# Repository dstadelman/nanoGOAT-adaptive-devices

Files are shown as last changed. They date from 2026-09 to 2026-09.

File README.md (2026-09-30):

# nanoGOAT Adaptive Devices

Open hardware that connects the [nanoGOAT AAC](https://nanogoat.com) app to the
physical world. Everything here is low-voltage, battery-powered, and built from
off-the-shelf parts so it can be reproduced at a kitchen table.

> **New here? Start with the [Adaptive Controller guide](adaptive-controller/README.md).**
> It takes you from nothing installed to a XIAO ESP32C6 board you can control
> over Bluetooth, and says which steps have not been tried yet.

Devices fall into two directions:

| Direction | Device | What it does | Status |
|---|---|---|---|
| **Output** (app → world) | [`adaptive-controller/`](adaptive-controller/) | A Bluetooth box with a 3.5mm jack. The app tells it to close a relay, which runs any switch-adapted toy (first up: a bubble machine). | Firmware works on a bare board; box build in progress |
| **Input** (world → app) | [`switch-interface/`](switch-interface/) | Lets a standard accessibility switch (e.g. a Big Red button) drive the tablet for switch scanning. | Idea |

## Vocabulary

- **Accessibility switch** (or *adaptive switch*): the big, easy-to-press button
  a person uses, e.g. AbleNet Big Red or Jelly Bean. It is just a momentary
  contact on a 3.5mm mono plug.
- **Switch-adapted toy**: a battery toy with a 3.5mm mono jack wired across its
  on/off switch. Shorting tip to sleeve runs the toy.
- **Switch interface**: a box that turns switch presses into input a tablet
  understands.

## Safety

Low voltage and battery toys only. Nothing mains-powered, ever.

## License

MIT, see [LICENSE](LICENSE).

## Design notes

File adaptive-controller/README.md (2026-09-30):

# Adaptive Controller

A small battery-powered Bluetooth box that lets the
[nanoGOAT AAC](https://nanogoat.com) app run a switch-adapted toy. A child taps
"more bubbles" on their communication board, the box closes a switch for a few
seconds, and the bubble machine runs.

The box plugs into a toy through a standard 3.5mm headphone-size jack. This is
the same plug that accessibility switches such as the AbleNet Big Red use.

## Where this project is

The firmware runs on a bare XIAO ESP32C6 board, and a computer can control it
over Bluetooth. The box itself (relay, battery, jack, enclosure) is designed
but not yet built.

This guide lists only steps that were done and checked, on **Windows 11**.
[What has not been tried yet](#what-has-not-been-tried-yet) lists the rest.

## 1. What you need

| Item | Notes |
|---|---|
| **Seeed Studio XIAO ESP32C6** | Make sure it says **ESP32C6**. Other XIAO boards need different settings. |
| **USB-C cable** | It must carry data, not only charge. |
| **A Windows computer** | About **8 GB** of free disk space for the tools, and Bluetooth for step 5. |

No soldering is needed for this guide. The board's small **orange LED** stands
in for the toy.

## 2. Install Arduino IDE

Arduino IDE turns the firmware source code into a program the board can run,
and copies it onto the board.

1. Download **Arduino IDE 2** from <https://www.arduino.cc/en/software> and
   install it. (Used here: version 2.3.10.)
2. Open it once, then close it.

Arduino IDE includes a command-line program, `arduino-cli`, which this guide
uses. On Windows it is at:

```
%LOCALAPPDATA%\Programs\Arduino IDE\resources\app\lib\backend\resources\arduino-cli.exe
```

The commands below write `arduino-cli`. Type the full path above in its place,
in quotes, or add that folder to your PATH.

## 3. Add support for the ESP32-C6 chip

Arduino IDE only knows Arduino's own boards. The XIAO ESP32C6 uses an
**Espressif ESP32-C6** chip, so you install Espressif's **esp32** package. It
contains the **RISC-V compiler** that builds programs for the ESP32-C6's
processor, Espressif's chip libraries (including Bluetooth), and the tool that
copies programs onto the board.

In a terminal, run:

```sh
arduino-cli core install esp32:esp32 --additional-urls https://espressif.github.io/arduino-esp32/package_esp32_index.json
```

What to expect:

- The download is about **2 GB**. The installed package takes about **6.5 GB**.
  It includes compilers for other ESP32 chips that this project does not use.
- The largest file is the RISC-V compiler, about 670 MB. Here, the download
  failed partway once (`Download failed ... connection was aborted`). Running
  the same command again finished the install.

**It worked when** `arduino-cli core list` shows `esp32:esp32` (used here:
version 3.3.12).

## 4. Put the firmware on the board

"Firmware" is the program that runs on the board. It is in
[`firmware/adaptive_controller/`](firmware/adaptive_controller/).

1. Download this repository: on GitHub, click **Code → Download ZIP** and
   unzip it. Open a terminal in the `adaptive-controller` folder.
2. Plug the XIAO into the computer.
3. Find its port:

   ```sh
   arduino-cli board list
   ```

   The board appears as a `Serial Port (USB)`, for example `COM3`.
4. Build and upload, using your port in place of `COM3`:

   ```sh
   arduino-cli compile -b esp32:esp32:XIAO_ESP32C6:CDCOnBoot=cdc -u -p COM3 firmware/adaptive_controller
   ```

   `CDCOnBoot=cdc` lets the board print messages to the computer over USB.
   The first build takes a few minutes.

**It worked when** the output ends with `Hash of data verified.` and
`Hard resetting via RTS pin...`. No buttons on the board need to be pressed.

## 5. Check that it works

Install Python 3 from <https://www.python.org/downloads/>, then install the two
libraries the test scripts use:

```sh
pip install pyserial bleak
```

### 5a. Ask the board how it is

```sh
python tools/status.py COM3
```

**It worked when** you see a line like:

```
[  35686] STATUS fw=0.1.0 ble=advertising relay=off mode=idle last_off=boot battery_mv=0
```

`ble=advertising` means the board is waiting for a Bluetooth connection as
**nanoGOAT Controller**. `relay=off` means the toy output is off.

### 5b. Run the full Bluetooth test

[`tools/ble_smoke_test.py`](tools/ble_smoke_test.py) connects to the board over
the computer's Bluetooth, sends every command, and checks every safety rule it
can see from outside: a timed run ends on its own, the 60-second limit holds,
and the output turns off when the connection drops.

```sh
python tools/ble_smoke_test.py --serial COM3
```

Add `--long` to also wait out the 60-second maximum run.

**It worked when** the last line says `ALL CHECKS PASSED`. While it runs, the
orange LED turns on and off.

### 5c. Measure how fast it answers

A child's tap has to start the toy in under 500 ms
([`_specs/PRODUCT.md`](_specs/PRODUCT.md) §4a).
[`tools/latency.py`](tools/latency.py) sends 20 short runs and times each one,
from sending the command until the box reports the relay is on.

```sh
python tools/latency.py
```

Measured here, over 100 runs from a Windows 11 PC: median **57 ms**, slowest
**139 ms**. The box's own log shows each relay closing in the same millisecond
its command arrives; the rest is Bluetooth.

The box accepts **one connection at a time**. If a tool says no Adaptive
Controller was found, a phone or another program is probably connected to it.
`python tools/status.py COM3` shows `ble=connected` in that case.

## What the lights mean

| Light | Meaning |
|---|---|
| **Orange** on | The toy output is on. With a toy plugged in, the toy runs. |
| **Orange** off | The toy output is off. |
| **Red** | Not yet identified. |

## Problems seen so far

| Problem | What fixed it |
|---|---|
| The esp32 install stopped with `Download failed` | Running the same install command again. |
| The board restarted every time a script closed its USB connection | On this chip, two USB control lines double as the reset line. The scripts in `tools/` now release them in an order that does not restart the board. A program that closes the port without doing this restarts the board; that is harmless. |

## What has not been tried yet

- Installing the board support and uploading through the Arduino IDE's
  windows and menus (this guide used the IDE's `arduino-cli`)
- The Arduino IDE Serial Monitor
- Controlling the board from a phone (for example with nRF Connect)
- Controlling the board from the nanoGOAT AAC app on a real phone or tablet
- macOS and Linux
- Wiring the relay, battery, jack, and status LED, and running a real toy
- Battery voltage measurement (the firmware reports `battery_mv=0` until the
  divider is built)

## Reference

| Path | Contents |
|---|---|
| [`_specs/`](_specs/README.md) | What the box does and must never do. The specs are normative: if anything else disagrees with them, the spec wins. |
| [`_specs/SAFETY.md`](_specs/SAFETY.md) | Read before connecting a battery or a toy |
| [`_specs/HARDWARE.md`](_specs/HARDWARE.md) | Pins, power, jack wiring, netlist |
| [`_specs/BOM.md`](_specs/BOM.md) | Parts list |
| [`_specs/BLE_PROTOCOL.md`](_specs/BLE_PROTOCOL.md) | Bluetooth commands and status format |
| [`kicad/`](kicad/) | KiCad 10 schematic ([PDF](kicad/adaptive-controller.pdf)) |
| [`firmware/`](firmware/) | Arduino firmware |
| [`tools/`](tools/) | `status.py`, `ble_smoke_test.py`, `latency.py` |

### Edit the schematic

Install [KiCad 10](https://www.kicad.org/download/) and open
`kicad/adaptive-controller.kicad_pro`. After editing, check it and re-export.
Run these in `kicad/`. On Windows, `kicad-cli` is in
`%LOCALAPPDATA%\Programs\KiCad\10.0\bin`.

```sh
kicad-cli sch erc adaptive-controller.kicad_sch
kicad-cli sch export svg -o . adaptive-controller.kicad_sch
kicad-cli sch export pdf -o adaptive-controller.pdf adaptive-controller.kicad_sch
kicad-cli sch export netlist -o adaptive-controller.net adaptive-controller.kicad_sch
python check_netlist.py adaptive-controller.net
```

### Build phases

Each phase adds its spec to `_specs/` and stops for review.

1. Hardware design and schematic ← *in review*
2. Toy adaptation: add a 3.5mm jack to the bubble machine
3. Firmware and BLE protocol ← *runs on a bare board; Bluetooth test passes*
4. Bench test
5. Enclosure layout

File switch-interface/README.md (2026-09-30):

# Switch Interface (idea, not started)

The input direction: a person presses an accessibility switch, and the tablet
treats it as a scanning input.

## Notes to resolve before designing

- **Where scanning lives.** Android (Switch Access) and iOS/iPadOS (Switch
  Control) both do switch scanning at the OS level. They accept a Bluetooth
  keyboard as the switch source. A box that shows up as a BLE HID keyboard and
  sends one key per switch press would then work with any app, with no app
  changes. The catch is that OS scanning only reaches controls the app exposes
  to the accessibility tree.
- **In-app scanning.** No switch-scanning code was found in `nanoGOAT-aac-app`
  as of 2026-09-30. If in-app scanning is wanted (it can be tuned for AAC grids),
  it's an app feature, and this box would still just be a keyboard.
- **Hardware overlap.** The same XIAO ESP32C6 plus a 3.5mm jack *input* (no
  relay) likely covers it. Two jacks give two-switch scanning (move + select).

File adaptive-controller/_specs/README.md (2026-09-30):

# `_specs` — Adaptive Controller specifications

**This folder is normative.** If firmware, wiring, issues, or videos disagree
with a spec, the spec wins. Fix the build or change the spec first.

## Folder laws

1. **Spec before build.** A behavior or wiring change starts as a spec edit,
   then an issue, then the build.
2. **Present tense only.** Specs describe what is true. No changelogs,
   strike-throughs, or "used to be." History lives in git and issues.
3. **One owner per fact.** Each fact has one spec. Other specs link to it
   instead of restating it.
4. **Issues name gaps.** Specs state the desired law. Issues state where the
   physical build or firmware diverges.

## Specs in this folder

| Spec | Owns |
|---|---|
| [PRODUCT](PRODUCT.md) | Goal, users, operating modes, status LED meanings, how the box is used day to day |
| [SAFETY](SAFETY.md) | Safety invariants that every other spec, the firmware and the wiring obey |
| [HARDWARE](HARDWARE.md) | Pin assignments, power path, current budget, output jack, netlist |
| [BOM](BOM.md) | Parts list and procurement status |
| [BLE_PROTOCOL](BLE_PROTOCOL.md) | GATT service, commands, and status format: the app ↔ box contract |
| [FIRMWARE](FIRMWARE.md) | Platform, timing values, state machine, indicators, serial log |

Specs still to come, one per build phase: toy adaptation (bubble machine),
bench test, enclosure.

## Precedence

| Domain | Winner |
|---|---|
| Anything that can leave a toy running or hurt someone | SAFETY |
| What the user sees and does | PRODUCT |
| What is wired to what | HARDWARE |
| Bytes between app and box | BLE_PROTOCOL |
| Timing values and firmware behavior | FIRMWARE |
| What to buy | BOM |

The KiCad schematic in [`../kicad/`](../kicad/) follows HARDWARE. If the two
disagree, HARDWARE wins.

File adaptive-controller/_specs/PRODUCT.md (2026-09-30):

# PRODUCT — Adaptive Controller

## 1. Goal

The Adaptive Controller lets the nanoGOAT AAC app run a switch-adapted toy.
A child taps a word such as "more bubbles" on their AAC board, and the toy runs.
The request is communicated with language, and the world responds.

## 2. What it is

A small battery-powered Bluetooth Low Energy (BLE) box with one 3.5mm mono
output jack. When the app commands it, the box closes a relay across the jack's
tip and sleeve for a bounded time.

This is the same electrical interface every commercial accessibility switch
uses (e.g. AbleNet Big Red). To a toy, the box is indistinguishable from a
person pressing a switch. Therefore:

- Any toy adapted for the box also works with an ordinary accessibility switch.
- Any commercially switch-adapted toy works with the box.

## 3. Users

| User | Needs |
|---|---|
| AAC user (child) | Taps a word; the toy responds quickly and reliably. |
| Caregiver / therapist | Charges the box, plugs in a toy, pairs it in the app, and trusts it will not leave a toy running. |
| Maker | Builds the box from the specs in this folder with hand tools and a soldering iron. |

## 4. Operating modes

The app selects the mode per command. [SAFETY](SAFETY.md) bounds every mode.

| Mode | Pairs with | Behavior |
|---|---|---|
| **Timed** (default) | A single word ("more bubbles") | The toy runs for a set duration, then stops. The box owns the timer; the app sends one command. |
| **Latched** | A word pair ("go" / "stop") | The toy runs until a stop command, disconnect, or the maximum on-time, whichever comes first. |
| **Direct** | Press-and-hold in the app | The toy runs only while the app keeps sending heartbeats. It stops as soon as heartbeats stop. |

The timed duration is a setting stored on the box. It is never longer than the
maximum on-time in [SAFETY](SAFETY.md).

## 4a. Response time

A child taps a word and expects the toy to answer at once. A delay the child
can notice breaks the link between the word and the result.

| Span | Limit |
|---|---|
| Tap on the AAC board → toy starts | under **500 ms** |
| Command arrives at the box → relay closed | under **50 ms** |

The app holds the connection open before the child taps. Connecting takes
seconds, so a tap never waits for a connection. Every command is sent the
moment it is tapped, never behind an earlier command that has not completed.

## 5. Status LED

One LED on the outside of the box shows the state.

| Pattern | Meaning |
|---|---|
| Slow blink | On, advertising, waiting for the app |
| Solid | Connected to the app |
| Quick flash | Relay on (toy running) |
| Rapid blink | Battery low; charge soon |
| Off | Power switch off, or battery empty |

## 6. Everyday use

- **Power:** a slide switch on the box turns it on and off. Off fully
  disconnects the battery.
- **Charging:** USB-C. The power switch must be **on** to charge, because the
  charger is on the controller board, downstream of the switch. The box works
  normally while charging.
- **Connecting a toy:** a 3.5mm mono cable runs from the box's jack to the toy's
  jack.
- **Connecting the app:** the app scans for the box and connects directly. The
  box needs no pairing in the phone's Bluetooth settings.

## 7. Scope

In scope: one output, battery toys, control from the nanoGOAT AAC app.

Out of scope: nanoGOAT app changes (the BLE protocol spec defines the contract
the app implements), multiple outputs, a physical switch input on the box,
custom PCB, and 3D-printed enclosure.

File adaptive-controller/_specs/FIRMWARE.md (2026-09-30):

# FIRMWARE — Adaptive Controller

Firmware behavior, timing values, and build. The wire format is owned by
[BLE_PROTOCOL](BLE_PROTOCOL.md); pins by [HARDWARE](HARDWARE.md); the
invariants it enforces by [SAFETY](SAFETY.md).

## 1. Platform

- **Arduino framework** on the Espressif `esp32` core, board **XIAO_ESP32C6**,
  built with `arduino-cli`. Seeed documents the XIAO ESP32C6 Arduino-first, the
  core includes BLE, and viewers can build it from the Arduino IDE.
- Source: [`../firmware/adaptive_controller/`](../firmware/adaptive_controller/).
- USB CDC on boot is enabled, so serial logs appear on the USB-C port.

## 2. Values

| Value | Setting |
|---|---|
| Hard maximum on-time | **60 s**, compiled in |
| Default timed duration | **5 s**, changeable with SET_DEFAULT_DURATION |
| Heartbeat timeout (direct mode) | **1500 ms** |
| Low-battery warning | below **3.60 V** |
| Low-battery cutoff (relay refuses to turn on) | below **3.40 V** |
| STATE notify while on | every **1 s** |

## 3. State machine

One loop owns the relay pin. Every path that turns the relay on goes through a
single function that checks the battery cutoff and sets a deadline no later
than *now + hard maximum*. The loop turns the relay off when any deadline passes
(timer, maximum on-time, heartbeat) and records the reason.

| From | Event | To |
|---|---|----|
| any | boot | idle (relay off, reason `boot`) |
| idle | RUN_TIMED / RUN_LATCHED / TOGGLE / HOLD | timed / latched / latched / direct |
| on (any mode) | another run command | the new mode; deadlines recomputed; maximum on-time counts from this command |
| on (any mode) | OFF, TOGGLE, deadline passed, disconnect, battery below cutoff, error | idle |

The first statement in `setup()` drives the relay pin low. The hardware
pull-down ([HARDWARE](HARDWARE.md) §3) covers the time before that.

## 4. Indicators

- **Status LED (D9):** the patterns in [PRODUCT](PRODUCT.md) §5.
- **Onboard user LED (GPIO15):** mirrors the relay. It is lit while the relay
  is on. This lets the firmware and app be tested on a bare XIAO with nothing
  wired to it.

## 5. Battery sensing

Battery sensing is a build option, `BATTERY_SENSE`. With it off (bare-board
builds without the divider), `battery_mv` reports `0` and the low-battery rules
are skipped. With it on, the firmware averages 16 ADC samples of VSENSE and
doubles them (1:2 divider).

## 6. Serial log

115200 baud over USB. One line per event, prefixed with milliseconds since
boot, so a test harness can parse it:

```
[   1234] BOOT fw=0.1.0 proto=1
[   1240] ADV start
[   5012] CONNECT
[   6100] CMD RUN_TIMED 5000
[   6100] RELAY ON mode=timed remaining=5000
[  11100] RELAY OFF reason=timer
[  15000] DISCONNECT
```

Every relay transition, command, connection change, and rejected command is
logged.

Any input received over serial prints one `STATUS` line with the firmware
version, connection state, relay state, and battery reading. A person with a
Serial Monitor open can confirm the board is alive without pressing a button:

```
[  81234] STATUS fw=0.1.0 ble=advertising relay=off mode=idle last_off=boot battery_mv=0
```

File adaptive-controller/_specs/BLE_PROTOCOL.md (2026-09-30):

# BLE_PROTOCOL — Adaptive Controller

The wire contract between the box and any app. The nanoGOAT AAC app, nRF
Connect, and test scripts all speak exactly this. Timing values and the state
machine behind it are owned by [FIRMWARE](FIRMWARE.md).

## 1. Discovery and connection

- The box is a BLE peripheral. It accepts **one connection at a time** and
  resumes advertising when that connection ends.
- The advertising packet carries the **service UUID**. The scan response carries
  the device name **`nanoGOAT Controller`**. Apps discover the box by filtering
  on the service UUID, not on the name.
- No bonding or OS pairing. An app scans, connects, and uses the service
  directly.

## 2. GATT

Every UUID shares the base `54ce0000-eae9-4eb4-8f51-34fbe6573f4c`. Only the
first 16 bits differ.

| Item | UUID | Properties |
|---|---|---|
| Service | `54ce0001-eae9-4eb4-8f51-34fbe6573f4c` | |
| CONTROL | `54ce0002-eae9-4eb4-8f51-34fbe6573f4c` | Write, Write Without Response |
| STATE | `54ce0003-eae9-4eb4-8f51-34fbe6573f4c` | Read, Notify |

All multi-byte integers are **little-endian**.

## 3. CONTROL: commands

Byte 0 is the opcode. The box ignores and logs malformed commands; the relay
state does not change.

| Opcode | Name | Payload | Effect |
|---|---|---|---|
| `0x01` | RUN_TIMED | `u32 duration_ms` | Relay on for `duration_ms`, clamped to the maximum on-time. `0` means the stored default duration. Restarts the timer if already on. |
| `0x02` | RUN_LATCHED | — | Relay on until OFF, disconnect, or the maximum on-time. |
| `0x03` | OFF | — | Relay off immediately. |
| `0x04` | TOGGLE | — | Relay off if on; otherwise RUN_LATCHED. |
| `0x05` | HOLD | — | Direct mode. Relay on, and stays on only while HOLD arrives at least once per heartbeat timeout. Each HOLD resets the heartbeat timer, not the maximum on-time. |
| `0x10` | SET_DEFAULT_DURATION | `u32 duration_ms` | Stores the default timed duration (persists across power cycles), clamped to the maximum on-time. |

Example: run for 5 seconds = `01 88 13 00 00`.

## 4. STATE: status

17 bytes. Readable at any time. Notified on every change, and once per second
while the relay is on.

| Offset | Type | Field | Values |
|---|---|---|---|
| 0 | u8 | protocol_version | `1` |
| 1 | u8 | relay | `0` off · `1` on |
| 2 | u8 | mode | `0` idle · `1` timed · `2` latched · `3` direct |
| 3 | u8 | last_off_reason | `0` boot · `1` OFF command · `2` timer done · `3` max on-time · `4` heartbeat lost · `5` disconnect · `6` low battery · `7` error |
| 4 | u32 | remaining_ms | Time until the relay turns off on its own; `0` when off |
| 8 | u16 | battery_mv | Battery voltage in mV; `0` when not measured |
| 10 | u32 | default_duration_ms | Stored default for RUN_TIMED |
| 14 | u16 | heartbeat_timeout_ms | HOLD must arrive within this interval |
| 16 | u8 | max_on_s | Hard maximum on-time, in seconds |

## 5. App obligations

- Treat STATE as the only truth about the relay. Never assume a command took
  effect until STATE says so.
- In direct mode, send HOLD at **no more than half** the heartbeat timeout.
- The app is never needed to turn the relay off. The box turns it off on its
  own ([SAFETY](SAFETY.md) §2).

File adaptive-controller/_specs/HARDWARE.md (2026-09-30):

# HARDWARE — Adaptive Controller

Electrical design of the box. Parts and their status live in [BOM](BOM.md);
the invariants this design serves live in [SAFETY](SAFETY.md).

Schematic

## 1. Blocks

| Ref | Block | Role |
|-----|---|---|
| U1 | Seeed XIAO ESP32C6 | BLE, timing, battery charging (USB-C) |
| K1 | 3V relay module, optocoupler input, high-level trigger | Closes the output contacts |
| J1 | 3.5mm mono panel jack with tip switch | Output to the toy |
| BT1 | 3.7V 1000mAh LiPo, protected | Power |
| SW1 | SPDT slide switch, used as SPST | Power on/off |
| LED1 | 5mm LED, red, green or yellow | Status ([PRODUCT](PRODUCT.md) §5) |

The relay contacts provide the isolation between the box and the toy. On this
style of 3V module, the optocoupler and the coil share the controller's ground,
so the optocoupler does not add galvanic isolation. It limits the GPIO load to
the optocoupler's LED current.

## 2. Pin assignments

| XIAO pin | GPIO | Net | Function |
|---|---|-----|---|
| D10 | GPIO18 | RELAY_IN | Relay module IN. High = relay on. |
| D9 | GPIO20 | LED_DRV | Status LED through 220Ω |
| D0 / A0 | GPIO0 | VSENSE | Battery voltage, ADC1_CH0 |
| D1 | GPIO1 | — | Reserved for a future switch input (LP GPIO, can wake from deep sleep) |
| D2–D8 | | — | Unused |

Excluded pins and the reason for each:

| Pins | Reason |
|---|---|
| GPIO4, 5, 8, 9, 15 | ESP32-C6 strapping pins. GPIO9 is the BOOT button; GPIO15 is the onboard user LED. |
| D6 / D7 (GPIO16/17) | UART0 TX/RX. The ROM bootloader transmits on TX at every reset. |
| GPIO3, GPIO14 | Onboard RF switch. GPIO3 low enables it; GPIO14 selects the antenna (low = onboard ceramic). Firmware leaves them at their defaults. |
| GPIO12, 13 | USB-Serial-JTAG: flashing and serial logs |

D9 and D10 sit on the same header edge as 3V3 and GND, so the relay's three
wires run in parallel.

Sources: [Seeed XIAO ESP32C6 wiki][seeed] (pin map, RF switch, battery
sensing); [ESP-IDF GPIO reference, ESP32-C6][idf-gpio] (strapping pins,
USB-JTAG pins, ADC1 channels).

## 3. Relay drive

- RELAY_IN has a **10kΩ pull-down (R3)** to GND. During reset, the GPIO is not
  yet driven, and the pull-down holds the relay off. With a weak internal
  pull-up active, the pull-down keeps the input well below the optocoupler's
  turn-on voltage.
- The relay module is powered from the XIAO **3V3** pin. The 5V pin exists only
  on USB power and would overdrive a 3V coil.
- **C2, 100µF** across the module's VCC/GND supplies the coil inrush locally.
  This prevents a brownout when the coil energizes during a BLE transmit burst
  on a partly discharged battery.

## 4. Current budget

| Load | Current | Basis |
|---|---|---|
| Relay coil (Songle SRD-03VDC-SL-C class) | ~120mA while on | [Datasheet via LCSC][relay] |
| Relay module IN (optocoupler LED) | A few mA from the GPIO | Module-dependent |
| Status LED | ~6mA | (3.3V − ~2.0V) / 220Ω. Blue and white LEDs (Vf ≈ 3V) are too dim at 220Ω and are not used. |
| R3 while relay on | 0.33mA | 3.3V / 10kΩ |
| Battery divider | ~20µA | 4.2V / 200kΩ |
| ESP32-C6 with BLE | Tens of mA | Measured in the bench test |

The relay's must-operate voltage is 75% of nominal (≈2.25V), so the relay keeps
working as the 3V3 rail follows a discharging battery below 3.3V.

## 5. Power path

```
BT1 + ──JST──► SW1 ──► VBAT ──► XIAO BAT+ pad
                         └────► R1 100k ─┬─ R2 100k ──► GND
                                         ├─ C1 100nF ─► GND
                                         └──────────► D0/A0 (VSENSE)
BT1 − ──JST────────────────────► XIAO BAT− pad = GND
USB-C ─► XIAO: powers the board and charges BT1 through the BAT pads
```

- SW1 disconnects the battery from everything, including the divider. Off
  draws zero current.
- Charging requires SW1 on ([PRODUCT](PRODUCT.md) §6).
- The XIAO ESP32C6 charges at about 100mA ([cnx-software][cnx]). A flat 1000mAh
  cell takes about 10 hours.
- R1/R2 form the 1:2 divider Seeed specifies for battery sensing on A0: 4.2V
  full charge reads as 2.1V. C1 gives the ADC a low-impedance source.

## 6. Output jack

J1 has three lugs: **sleeve**, **tip**, and **tip switch**. The tip switch rests
against the tip spring with no plug inserted, and opens when a plug is inserted.
Lug positions differ between vendors. The builder identifies them with a
multimeter:

1. Sleeve: continuity to the threaded bushing.
2. Tip and tip switch: continuity to each other with no plug inserted.
3. Tip: continuity to the plug tip with a plug inserted. The tip switch goes open.

Relay **COM → tip**, relay **NO → sleeve**. Relay NC and the tip-switch lug are
not connected. Relay contacts have no polarity, so the orientation does not
affect the toy.

The box has a female jack. A 3.5mm mono male-to-male cable connects it to the
toy's female jack. This is the same arrangement commercial switch extension
cables use.

## 7. Netlist

| Net | Connections |
|-----|---|
| VBAT_RAW | BT1 + · SW1 common |
| VBAT | SW1 outer pin A · U1 BAT+ · R1.1 |
| GND | BT1 − · U1 BAT− · U1 GND · K1 GND · R2.2 · C1.2 · R3.2 · LED1 cathode · C2 − |
| 3V3 | U1 3V3 · K1 VCC · C2 + |
| VSENSE | R1.2 · R2.1 · C1.1 · U1 D0 |
| RELAY_IN | U1 D10 · K1 IN · R3.1 |
| LED_DRV | U1 D9 · R4.1 |
| LED_A | R4.2 · LED1 anode |
| OUT_TIP | K1 COM · J1 tip |
| OUT_SLEEVE | K1 NO · J1 sleeve |
| No connect | K1 NC · J1 tip switch · SW1 outer pin B |

## 8. Facts pending measurement on the physical parts

| Fact | Checked in |
|---|---|
| Relay part number (coil current) | Bench test |
| Relay module IN current | Bench test |
| J1 lug identities | Build procedure |
| Battery connector type (JST-PH 2.0) and polarity | Build procedure |
| XIAO ESP32C6 charge current | Bench test |

[seeed]: https://wiki.seeedstudio.com/xiao_esp32c6_getting_started/
[idf-gpio]: https://docs.espressif.com/projects/esp-idf/en/stable/esp32c6/api-reference/peripherals/gpio.html
[relay]: https://www.lcsc.com/product-detail/C24585.html
[cnx]: https://www.cnx-software.com/2024/05/22/tiny-xiao-esp32c6-wifi-ble-and-802-15-4-iot-board-offers-up-to-16-gpio-pins/

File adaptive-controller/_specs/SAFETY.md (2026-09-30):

# SAFETY — Adaptive Controller

These invariants override every other spec. A design that satisfies a feature
but breaks an invariant is wrong.

## 1. Electrical scope

- The box switches **low-voltage, battery-powered toys only.** It is never
  connected to anything mains-powered, directly or through an adapter.
- The toy's circuit touches only the relay contacts. The toy's battery and the
  box's electronics share no conductor.

## 2. The relay is off unless something keeps it on

The box never depends on an "off" message arriving. The relay is **off** in
each of these conditions:

| Condition | Mechanism |
|---|---|
| Power-up, reset, or brownout | Hardware: 10kΩ pull-down on the relay input ([HARDWARE](HARDWARE.md) §3). Firmware drives the pin low before it does anything else. |
| Maximum on-time reached, in any mode | Firmware timer, independent of the app |
| BLE disconnect | Firmware |
| Direct mode heartbeat missed | Firmware |
| Any firmware error or unexpected state | Firmware fails to off |
| Battery below the cutoff voltage | Firmware refuses to turn the relay on |

## 3. Maximum on-time

- A single, compiled-in **hard maximum on-time** caps every activation in every
  mode. No command or stored setting can exceed it.
- The user-adjustable timed duration and any latched run are clamped to it.
- After the relay turns off at the hard maximum, it stays off until a new,
  separate command arrives. Nothing re-triggers it automatically.

The specific values (hard maximum, default timed duration, heartbeat interval,
battery cutoff) are owned by the firmware spec.

## 4. Battery

- The LiPo has its own protection circuit.
- JST battery connectors have no standard polarity. The battery connector's
  polarity is checked with a multimeter before the battery is ever connected
  to the controller board.
- The battery is never charged unattended while damaged, swollen, or hot.

## 5. Toy side

- Solder joints and the added jack inside a toy are sealed so bubble solution
  or other liquid cannot reach them.
- Adding the jack leaves the toy's own switch working.

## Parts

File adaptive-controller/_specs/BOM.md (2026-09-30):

# BOM — Adaptive Controller

Reference designators match [HARDWARE](HARDWARE.md).

**Status:** **Have** = in hand or ordered · **Planned** = chosen, not ordered ·
**Needed** = required by the design, not yet chosen or ordered.

## Box

| Ref | Part | Qty | Status |
|-----|---|-----|---|
| U1 | Seeed XIAO ESP32C6 | 1 | Have (3-pack) |
| K1 | AITRIP 3V 1-channel relay module, optocoupler, high-level trigger | 1 | Have (8-pack) |
| BT1 | 3.7V 1000mAh LiPo, 802540, protected, JST | 1 | Have |
| J1 | CESS 3.5mm mono panel jack with switch | 1 | Have (10-pack) |
| SW1 | SS12F15 SPDT mini slide switch | 1 | Have |
| | Female pin headers, to socket U1 | 2 × 7-pin | Have |
| | 22 AWG silicone stranded wire | | Have (6 colors) |
| LED1 | 5mm diffused LED, red, green or yellow | 1 | Planned |
| R4 | 220Ω resistor | 1 | Planned |
| | 5mm chrome LED bezel, 8mm hole | 1 | Planned |
| | uxcell 100×68×50mm clear ABS enclosure | 1 | Planned |
| | 5×7cm double-sided perfboard | 1 | Planned |
| | JST-PH 2.0 mating pigtail for BT1 | 1 | Planned (confirm the battery's connector is PH 2.0 first) |
| R3 | 10kΩ resistor | 1 | **Needed** |
| R1, R2 | 100kΩ resistor | 2 | **Needed** |
| C1 | 100nF ceramic capacitor | 1 | **Needed** |
| C2 | 100µF electrolytic capacitor, ≥10V | 1 | **Needed** |

A basic resistor and capacitor assortment kit covers every **Needed** item.

## Cables, toy and test equipment

| Part | Qty | Status |
|---|-----|---|
| Fancasee 3.5mm mono male plug pigtails (toy wiring, bench cables) | | Have (10-pack) |
| Breadboards and jumper wires (bench build) | | Have |
| 3.5mm mono male-to-male cable, box to toy | 1 | Planned |
| Babrit battery bubble machine | 1 | Planned |
| AbleNet Big Red switch (reference switch) | 1 | Planned |
| Multimeter | 1 | Assumed on hand |

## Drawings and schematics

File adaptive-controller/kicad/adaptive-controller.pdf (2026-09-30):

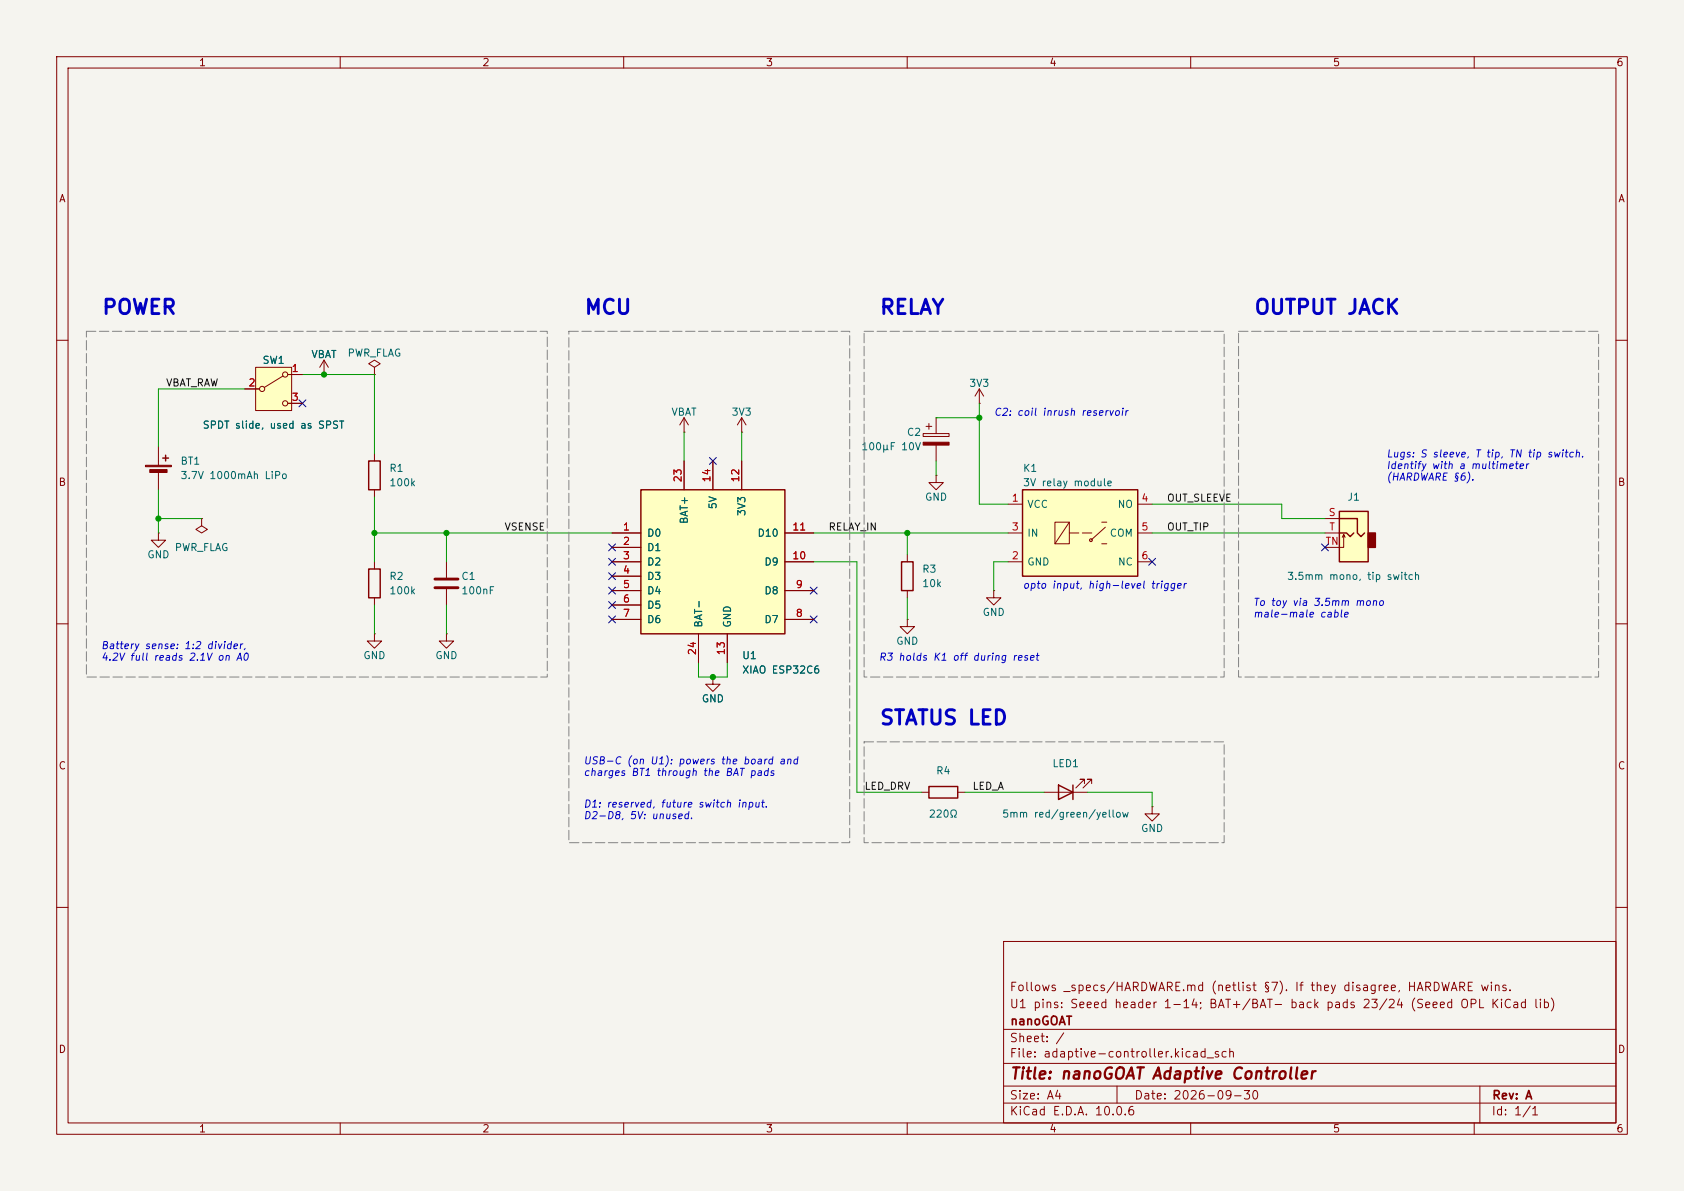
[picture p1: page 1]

SPDT slide, used as SPST 1

SPDT slide, used as SPST BT1

Lugs: S sleeve, T tip, TN tip switch.

Identify with a multimeter (HARDWARE §6). USB-C (on U1): powers the board and

3.5mm mono, tip switch GND

To toy via 3.5mm mono male-male cable Battery sense: 1:2 divider, 4.2V full reads 2.1V on A0

R3 holds K1 off during reset STATUS LED

Follows _specs/HARDWARE.md (netlist §7). If they disagree, HARDWARE wins.
U1 pins: Seeed header 1-14; BAT+/BAT- back pads 23/24 (Seeed OPL KiCad lib)
nanoGOAT
Sheet: /
File: adaptive-controller.kicad_sch
Title: nanoGOAT Adaptive Controller

Size: A4 | Rev: A
KiCad E.D.A. 10.0.6 | Id: 1/1

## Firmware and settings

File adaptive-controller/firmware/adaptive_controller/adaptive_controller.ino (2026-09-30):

// nanoGOAT Adaptive Controller firmware.
//
// Behavior: _specs/FIRMWARE.md   Wire format: _specs/BLE_PROTOCOL.md
// Pins:     _specs/HARDWARE.md   Invariants:  _specs/SAFETY.md
//
// BLE callbacks never touch the relay. They queue events; loop() is the single
// owner of the relay pin and applies every deadline.

#include <BLEDevice.h>
#include <BLEServer.h>
#include <Preferences.h>

#define FW_VERSION "0.1.0"
#define PROTOCOL_VERSION 1

// Set to 1 once the R1/R2 divider is wired to A0 (FIRMWARE.md §5).
#ifndef BATTERY_SENSE
#define BATTERY_SENSE 0
#endif

// ---- Pins (HARDWARE.md §2) ----
static const int PIN_RELAY = D10;       // GPIO18, high = relay on
static const int PIN_STATUS_LED = D9;   // GPIO20, high = lit
static const int PIN_VSENSE = A0;       // GPIO0, battery / 2
static const int PIN_ONBOARD_LED = 15;  // user LED, active low, mirrors relay

// ---- Values (FIRMWARE.md §2) ----
static const uint32_t MAX_ON_MS = 60000;
static const uint8_t MAX_ON_S = MAX_ON_MS / 1000;
static const uint32_t DEFAULT_DURATION_MS = 5000;
static const uint16_t HEARTBEAT_TIMEOUT_MS = 1500;
static const uint16_t LOW_BATTERY_WARN_MV = 3600;
static const uint16_t LOW_BATTERY_CUTOFF_MV = 3400;
static const uint32_t NOTIFY_WHILE_ON_MS = 1000;

// ---- Protocol (BLE_PROTOCOL.md) ----
#define SERVICE_UUID "54ce0001-eae9-4eb4-8f51-34fbe6573f4c"
#define CONTROL_UUID "54ce0002-eae9-4eb4-8f51-34fbe6573f4c"
#define STATE_UUID "54ce0003-eae9-4eb4-8f51-34fbe6573f4c"
#define DEVICE_NAME "nanoGOAT Controller"

enum Opcode : uint8_t {
  OP_RUN_TIMED = 0x01,
  OP_RUN_LATCHED = 0x02,
  OP_OFF = 0x03,
  OP_TOGGLE = 0x04,
  OP_HOLD = 0x05,
  OP_SET_DEFAULT_DURATION = 0x10,
};

enum Mode : uint8_t { MODE_IDLE = 0, MODE_TIMED = 1, MODE_LATCHED = 2, MODE_DIRECT = 3 };

enum OffReason : uint8_t {
  OFF_BOOT = 0,
  OFF_COMMAND = 1,
  OFF_TIMER = 2,
  OFF_MAX_ON = 3,
  OFF_HEARTBEAT = 4,
  OFF_DISCONNECT = 5,
  OFF_LOW_BATTERY = 6,
  OFF_ERROR = 7,
};

static const char *MODE_NAMES[] = {"idle", "timed", "latched", "direct"};
static const char *REASON_NAMES[] = {"boot", "command", "timer", "max_on",
                                     "heartbeat", "disconnect", "low_battery", "error"};

// Events handed from BLE callbacks to loop().
enum EventType : uint8_t { EV_COMMAND, EV_CONNECT, EV_DISCONNECT };
struct Event {
  EventType type;
  uint8_t len;
  uint8_t data[8];
};

static QueueHandle_t events;
static BLECharacteristic *stateChar;
static Preferences prefs;

// ---- Relay state, owned by loop() ----
static bool relayOn = false;
static Mode mode = MODE_IDLE;
static OffReason lastOffReason = OFF_BOOT;
static uint32_t maxOnDeadline = 0;     // absolute millis
static uint32_t modeDeadline = 0;      // timer end (timed) or heartbeat end (direct)
static bool connected = false;
static uint32_t defaultDurationMs = DEFAULT_DURATION_MS;
static uint16_t batteryMv = 0;
static bool stateDirty = true;
static uint32_t lastNotify = 0;

static void logf(const char *fmt, ...) {
  char buf[160];
  va_list args;
  va_start(args, fmt);
  vsnprintf(buf, sizeof(buf), fmt, args);
  va_end(args);
  Serial.printf("[%7lu] %s\n", (unsigned long)millis(), buf);
}

static bool deadlinePassed(uint32_t deadline, uint32_t now) {
  return (int32_t)(now - deadline) >= 0;
}

static uint32_t remainingMs(uint32_t now) {
  if (!relayOn) return 0;
  uint32_t end = maxOnDeadline;
  if ((mode == MODE_TIMED || mode == MODE_DIRECT) && (int32_t)(modeDeadline - end) < 0) {
    end = modeDeadline;
  }
  return deadlinePassed(end, now) ? 0 : end - now;
}

static void writeRelay(bool on) {
  digitalWrite(PIN_RELAY, on ? HIGH : LOW);
  digitalWrite(PIN_ONBOARD_LED, on ? LOW : HIGH);
}

static void relayOff(OffReason reason) {
  writeRelay(false);
  if (relayOn) logf("RELAY OFF reason=%s", REASON_NAMES[reason]);
  relayOn = false;
  mode = MODE_IDLE;
  lastOffReason = reason;
  stateDirty = true;
}

// The only path that turns the relay on (FIRMWARE.md §3).
static void relayOn_(Mode newMode, uint32_t modeMs, uint32_t now) {
  if (BATTERY_SENSE && batteryMv != 0 && batteryMv < LOW_BATTERY_CUTOFF_MV) {
    logf("REJECT run: battery %umV below cutoff", batteryMv);
    relayOff(OFF_LOW_BATTERY);
    return;
  }
  maxOnDeadline = now + MAX_ON_MS;
  modeDeadline = now + min(modeMs, MAX_ON_MS);
  mode = newMode;
  relayOn = true;
  writeRelay(true);
  lastOffReason = OFF_BOOT;  // not meaningful while on; reported only after the next off
  stateDirty = true;
  logf("RELAY ON mode=%s remaining=%lu", MODE_NAMES[mode], (unsigned long)remainingMs(now));
}

static uint32_t readU32(const uint8_t *p) {
  return (uint32_t)p[0] | ((uint32_t)p[1] << 8) | ((uint32_t)p[2] << 16) | ((uint32_t)p[3] << 24);
}

static void handleCommand(const Event &ev, uint32_t now) {
  if (ev.len == 0) {
    logf("REJECT empty command");
    return;
  }
  uint8_t op = ev.data[0];
  switch (op) {
    case OP_RUN_TIMED: {
      if (ev.len != 5) break;
      uint32_t ms = readU32(ev.data + 1);
      if (ms == 0) ms = defaultDurationMs;
      logf("CMD RUN_TIMED %lu", (unsigned long)ms);
      relayOn_(MODE_TIMED, ms, now);
      return;
    }
    case OP_RUN_LATCHED:
      if (ev.len != 1) break;
      logf("CMD RUN_LATCHED");
      relayOn_(MODE_LATCHED, MAX_ON_MS, now);
      return;
    case OP_OFF:
      if (ev.len != 1) break;
      logf("CMD OFF");
      relayOff(OFF_COMMAND);
      return;
    case OP_TOGGLE:
      if (ev.len != 1) break;
      logf("CMD TOGGLE");
      if (relayOn) relayOff(OFF_COMMAND);
      else relayOn_(MODE_LATCHED, MAX_ON_MS, now);
      return;
    case OP_HOLD:
      if (ev.len != 1) break;
      if (relayOn && mode == MODE_DIRECT) {
        // Heartbeat: extend the heartbeat deadline only, never the max on-time.
        modeDeadline = now + HEARTBEAT_TIMEOUT_MS;
      } else {
        logf("CMD HOLD");
        relayOn_(MODE_DIRECT, HEARTBEAT_TIMEOUT_MS, now);
      }
      return;
    case OP_SET_DEFAULT_DURATION: {
      if (ev.len != 5) break;
      uint32_t ms = min(readU32(ev.data + 1), MAX_ON_MS);
      if (ms == 0) break;
      defaultDurationMs = ms;
      prefs.putULong("default_ms", ms);
      stateDirty = true;
      logf("CMD SET_DEFAULT_DURATION %lu", (unsigned long)ms);
      return;
    }
  }
  logf("REJECT op=0x%02X len=%u", op, ev.len);
}

// ---- BLE ----

class ServerCallbacks : public BLEServerCallbacks {
  void onConnect(BLEServer *) override {
    Event ev = {EV_CONNECT, 0, {}};
    xQueueSend(events, &ev, 0);
  }
  void onDisconnect(BLEServer *) override {
    // Queued to loop(); the relay turns off within one loop pass.
    Event ev = {EV_DISCONNECT, 0, {}};
    xQueueSend(events, &ev, 0);
  }
};

class ControlCallbacks : public BLECharacteristicCallbacks {
  void onWrite(BLECharacteristic *c) override {
    String v = c->getValue();
    Event ev = {EV_COMMAND, 0, {}};
    if (v.length() > sizeof(ev.data)) {
      ev.len = 0xFF;  // oversized: rejected in loop()
    } else {
      ev.len = v.length();
      memcpy(ev.data, v.c_str(), v.length());
    }
    xQueueSend(events, &ev, 0);
  }
};

static void publishState(uint32_t now) {
  uint8_t s[17];
  uint32_t rem = remainingMs(now);
  s[0] = PROTOCOL_VERSION;
  s[1] = relayOn ? 1 : 0;
  s[2] = mode;
  s[3] = lastOffReason;
  memcpy(s + 4, &rem, 4);
  memcpy(s + 8, &batteryMv, 2);
  memcpy(s + 10, &defaultDurationMs, 4);
  uint16_t hb = HEARTBEAT_TIMEOUT_MS;
  memcpy(s + 14, &hb, 2);
  s[16] = MAX_ON_S;
  stateChar->setValue(s, sizeof(s));
  if (connected) stateChar->notify();
  lastNotify = now;
  stateDirty = false;
}

static void setupBle() {
  BLEDevice::init(DEVICE_NAME);
  BLEServer *server = BLEDevice::createServer();
  server->setCallbacks(new ServerCallbacks());
  BLEService *service = server->createService(SERVICE_UUID);

  BLECharacteristic *control = service->createCharacteristic(
      CONTROL_UUID, BLECharacteristic::PROPERTY_WRITE | BLECharacteristic::PROPERTY_WRITE_NR);
  control->setCallbacks(new ControlCallbacks());

  stateChar = service->createCharacteristic(
      STATE_UUID, BLECharacteristic::PROPERTY_READ | BLECharacteristic::PROPERTY_NOTIFY);
  // The BLE stack adds the notify descriptor (CCCD) itself.

  service->start();

  BLEAdvertising *adv = BLEDevice::getAdvertising();
  adv->addServiceUUID(SERVICE_UUID);
  adv->setScanResponse(true);  // name goes in the scan response (BLE_PROTOCOL.md §1)
  BLEDevice::startAdvertising();
  logf("ADV start");
}

// ---- Battery ----

static void sampleBattery() {
#if BATTERY_SENSE
  uint32_t sum = 0;
  for (int i = 0; i < 16; i++) sum += analogReadMilliVolts(PIN_VSENSE);
  uint16_t mv = (sum / 16) * 2;
  if (mv / 50 != batteryMv / 50) stateDirty = true;  // notify on 50mV steps
  batteryMv = mv;
#endif
}

static bool batteryLow() {
  return BATTERY_SENSE && batteryMv != 0 && batteryMv < LOW_BATTERY_WARN_MV;
}

// ---- Status LED (PRODUCT.md §5) ----

static void updateStatusLed(uint32_t now) {
  bool lit;
  if (relayOn) lit = (now / 60) % 2;             // quick flash
  else if (batteryLow()) lit = (now / 125) % 2;  // rapid blink
  else if (connected) lit = true;                // solid
  else lit = (now / 1000) % 2;                   // slow blink
  digitalWrite(PIN_STATUS_LED, lit ? HIGH : LOW);
}

// ---- Serial status (FIRMWARE.md §6) ----

// Any input from a Serial Monitor prints a STATUS line, so a person can see
// the board is alive without pressing a button. One message (with or without
// a line ending) prints one line.
static void handleSerialInput() {
  if (Serial.available() <= 0) return;
  delay(20);  // let the rest of the message arrive
  while (Serial.available() > 0) Serial.read();
  logf("STATUS fw=%s ble=%s relay=%s mode=%s last_off=%s battery_mv=%u", FW_VERSION,
       connected ? "connected" : "advertising", relayOn ? "on" : "off", MODE_NAMES[mode],
       REASON_NAMES[lastOffReason], batteryMv);
}

// ---- Main ----

void setup() {
  // Relay off before anything else (SAFETY.md §2).
  pinMode(PIN_RELAY, OUTPUT);
  digitalWrite(PIN_RELAY, LOW);
  pinMode(PIN_ONBOARD_LED, OUTPUT);
  digitalWrite(PIN_ONBOARD_LED, HIGH);
  pinMode(PIN_STATUS_LED, OUTPUT);
  digitalWrite(PIN_STATUS_LED, LOW);

  Serial.begin(115200);
  delay(300);  // give USB CDC a moment so the boot line is not lost
  logf("BOOT fw=%s proto=%d battery_sense=%d", FW_VERSION, PROTOCOL_VERSION, BATTERY_SENSE);

  events = xQueueCreate(16, sizeof(Event));
  prefs.begin("controller", false);
  defaultDurationMs = min((uint32_t)prefs.getULong("default_ms", DEFAULT_DURATION_MS), MAX_ON_MS);

#if BATTERY_SENSE
  analogSetAttenuation(ADC_11db);
#endif
  sampleBattery();
  setupBle();
  publishState(millis());
}

void loop() {
  uint32_t now = millis();

  Event ev;
  while (xQueueReceive(events, &ev, 0) == pdTRUE) {
    switch (ev.type) {
      case EV_CONNECT:
        connected = true;
        stateDirty = true;
        logf("CONNECT");
        break;
      case EV_DISCONNECT:
        connected = false;
        logf("DISCONNECT");
        relayOff(OFF_DISCONNECT);
        BLEDevice::startAdvertising();
        logf("ADV start");
        break;
      case EV_COMMAND:
        handleCommand(ev, now);
        break;
    }
  }

  if (relayOn) {
    if (deadlinePassed(maxOnDeadline, now)) {
      relayOff(OFF_MAX_ON);
    } else if (mode == MODE_TIMED && deadlinePassed(modeDeadline, now)) {
      relayOff(OFF_TIMER);
    } else if (mode == MODE_DIRECT && deadlinePassed(modeDeadline, now)) {
      relayOff(OFF_HEARTBEAT);
    }
  }

  static uint32_t lastBattery = 0;
  if (now - lastBattery >= 1000) {
    lastBattery = now;
    sampleBattery();
    if (relayOn && BATTERY_SENSE && batteryMv != 0 && batteryMv < LOW_BATTERY_CUTOFF_MV) {
      relayOff(OFF_LOW_BATTERY);
    }
  }

  if (stateDirty || (relayOn && now - lastNotify >= NOTIFY_WHILE_ON_MS)) {
    publishState(now);
  }

  handleSerialInput();
  updateStatusLed(now);
  delay(5);
}

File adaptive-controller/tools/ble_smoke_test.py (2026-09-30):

"""Drives an Adaptive Controller over BLE and checks every rule it can observe.

    pip install bleak pyserial
    python ble_smoke_test.py                 # BLE checks only
    python ble_smoke_test.py --serial COM3   # also prints the box's serial log
    python ble_smoke_test.py --long          # adds the 60 s maximum on-time check

Checks the wire format in ../_specs/BLE_PROTOCOL.md and the off rules in
../_specs/SAFETY.md §2. Relay state is read only from STATE, never assumed.
"""
import argparse
import asyncio
import struct
import sys
import threading
import time

from bleak import BleakClient, BleakScanner

SERVICE = "54ce0001-eae9-4eb4-8f51-34fbe6573f4c"
CONTROL = "54ce0002-eae9-4eb4-8f51-34fbe6573f4c"
STATE = "54ce0003-eae9-4eb4-8f51-34fbe6573f4c"

MODES = ["idle", "timed", "latched", "direct"]
REASONS = ["boot", "command", "timer", "max_on", "heartbeat", "disconnect",
           "low_battery", "error"]

RUN_TIMED = lambda ms: struct.pack("<BI", 0x01, ms)
RUN_LATCHED = bytes([0x02])
OFF = bytes([0x03])
TOGGLE = bytes([0x04])
HOLD = bytes([0x05])
SET_DEFAULT = lambda ms: struct.pack("<BI", 0x10, ms)

T0 = time.monotonic()
failures = []


def log(tag, msg):
    print(f"{time.monotonic() - T0:7.2f}  {tag:6} {msg}", flush=True)


def parse(value):
    (ver, relay, mode, reason, remaining, mv, default_ms, hb_ms, max_s) = \
        struct.unpack("<BBBBIHIHB", bytes(value))
    return dict(version=ver, relay=bool(relay), mode=MODES[mode],
                reason=REASONS[reason], remaining=remaining, battery_mv=mv,
                default_ms=default_ms, heartbeat_ms=hb_ms, max_on_s=max_s)


def check(name, ok, detail=""):
    log("PASS" if ok else "FAIL", f"{name} {detail}".rstrip())
    if not ok:
        failures.append(name)


def tail_serial(port, stop):
    import serial
    try:
        s = serial.Serial(port, 115200, timeout=0.2)
    except Exception as e:  # noqa: BLE001 - report and carry on without logs
        log("SERIAL", f"not opened: {e}")
        return
    while not stop.is_set():
        line = s.readline()
        if line:
            log("BOX", line.decode(errors="replace").rstrip())
    # RTS/DTR double as the ESP32-C6 reset line; a plain close restarts the box.
    s.rts = False
    s.dtr = False
    s.close()


class Box:
    def __init__(self, client):
        self.client = client
        self.state = None
        self.changed = asyncio.Event()

    async def start(self):
        await self.client.start_notify(STATE, self._on_state)
        self.state = parse(await self.client.read_gatt_char(STATE))

    def _on_state(self, _, value):
        self.state = parse(value)
        self.changed.set()

    async def send(self, data, response=True):
        await self.client.write_gatt_char(CONTROL, data, response=response)

    async def wait_for(self, predicate, timeout):
        end = time.monotonic() + timeout
        while not predicate(self.state):
            left = end - time.monotonic()
            if left <= 0:
                return False
            self.changed.clear()
            try:
                await asyncio.wait_for(self.changed.wait(), left)
            except asyncio.TimeoutError:
                return predicate(self.state)
        return True


async def find():
    log("BLE", "scanning for the controller service…")
    device = await BleakScanner.find_device_by_filter(
        lambda d, adv: SERVICE in [u.lower() for u in adv.service_uuids],
        timeout=10)
    if device is None:
        log("FAIL", "no Adaptive Controller found")
        sys.exit(1)
    log("BLE", f"found {device.name} {device.address}")
    return device


async def run(long_test):
    device = await find()

    async with BleakClient(device) as client:
        box = Box(client)
        await box.start()
        s = box.state
        log("STATE", s)
        check("protocol version is 1", s["version"] == 1)
        check("relay off after connect", not s["relay"])

        # Timed run ends by itself.
        await box.send(RUN_TIMED(2000))
        check("RUN_TIMED 2 s turns relay on",
              await box.wait_for(lambda s: s["relay"] and s["mode"] == "timed", 2))
        check("timed run ends on its own",
              await box.wait_for(lambda s: not s["relay"], 3.5))
        check("off reason is timer", box.state["reason"] == "timer",
              box.state["reason"])

        # Latched run ends on OFF.
        await box.send(RUN_LATCHED)
        check("RUN_LATCHED turns relay on",
              await box.wait_for(lambda s: s["relay"] and s["mode"] == "latched", 2))
        await asyncio.sleep(1)
        await box.send(OFF)
        check("OFF turns relay off", await box.wait_for(lambda s: not s["relay"], 2))
        check("off reason is command", box.state["reason"] == "command")

        # TOGGLE twice.
        await box.send(TOGGLE)
        check("TOGGLE on", await box.wait_for(lambda s: s["relay"], 2))
        await box.send(TOGGLE)
        check("TOGGLE off", await box.wait_for(lambda s: not s["relay"], 2))

        # Direct mode: on while HOLD arrives, off when it stops.
        for _ in range(6):
            await box.send(HOLD, response=False)
            await asyncio.sleep(0.5)
        check("HOLD keeps relay on", box.state["relay"] and box.state["mode"] == "direct")
        stopped = time.monotonic()
        check("relay off after heartbeats stop",
              await box.wait_for(lambda s: not s["relay"], 3))
        lapse = time.monotonic() - stopped
        check("off reason is heartbeat", box.state["reason"] == "heartbeat",
              f"after {lapse:.2f} s")

        # Malformed command is ignored.
        await box.send(bytes([0x01, 0x10]))
        await box.send(bytes([0x7F]))
        await asyncio.sleep(0.5)
        check("malformed commands leave relay off", not box.state["relay"])

        # Stored default duration round-trips.
        await box.send(SET_DEFAULT(3000))
        check("SET_DEFAULT_DURATION 3 s",
              await box.wait_for(lambda s: s["default_ms"] == 3000, 2))
        await box.send(SET_DEFAULT(5000))
        await box.wait_for(lambda s: s["default_ms"] == 5000, 2)

        # Clamp: a request longer than the maximum is capped.
        await box.send(RUN_TIMED(600_000))
        await box.wait_for(lambda s: s["relay"], 2)
        cap = box.state["max_on_s"] * 1000
        check("RUN_TIMED is clamped to max on-time",
              box.state["remaining"] <= cap, f"remaining={box.state['remaining']}")
        if long_test:
            check("max on-time ends the run",
                  await box.wait_for(lambda s: not s["relay"], cap / 1000 + 3))
            check("off reason is max_on", box.state["reason"] == "max_on")
        else:
            await box.send(OFF)
            await box.wait_for(lambda s: not s["relay"], 2)
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

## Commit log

2026-09-30 Adaptive Controller: specs, KiCad schematic, firmware, BLE test
    A battery-powered BLE box that lets nanoGOAT AAC run switch-adapted toys
    through a 3.5mm mono jack (the standard accessibility-switch interface).
    - _specs/: PRODUCT, SAFETY, HARDWARE, BOM, BLE_PROTOCOL, FIRMWARE
    - kicad/: KiCad 10 schematic (ERC clean) + netlist check against HARDWARE
    - firmware/: Arduino (esp32 core) for the Seeed XIAO ESP32C6; timed,
    latched and direct modes, hard 60 s max on-time, relay off on
    disconnect, heartbeat loss, reset
    - tools/ble_smoke_test.py: drives every command over BLE and checks the
    off rules, with the box's serial log interleaved
    - switch-interface/: notes for the input-side device
    Co-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
    [adaptive-controller.kicad_sch]
2026-09-30 docs: beginner getting-started guide for the Adaptive Controller
    Walks a newcomer from nothing installed to a working board: Arduino IDE,
    the Espressif esp32 package (RISC-V compiler, ~2 GB download / 6.5 GB
    installed), board settings, upload, serial log, nRF Connect test, PC
    smoke test, and troubleshooting. Root README points new readers there.
2026-09-30 Adaptive Controller: guide states only what was done; STATUS on serial
    - README: cut to the steps actually done and checked on Windows 11
    (arduino-cli from Arduino IDE 2.3.10, esp32 core 3.3.12, upload,
    status check, BLE smoke test), plus a list of what has not been tried
    - Firmware: any serial input prints one STATUS line (FIRMWARE.md §6), so
    the board can be checked without pressing a button
    - tools/status.py: asks the board for its STATUS line
    - tools: release RTS before DTR on close; a plain close resets the
    ESP32-C6 through its USB-Serial-JTAG reset lines
    [adaptive_controller.ino, ble_smoke_test.py, status.py]
2026-09-30 spec: response time — tap to toy under 500 ms
2026-09-30 tools: latency.py; guide records measured response time
    100 runs from a Windows 11 PC: median 57 ms, max 139 ms, command sent to
    relay-on status received.
